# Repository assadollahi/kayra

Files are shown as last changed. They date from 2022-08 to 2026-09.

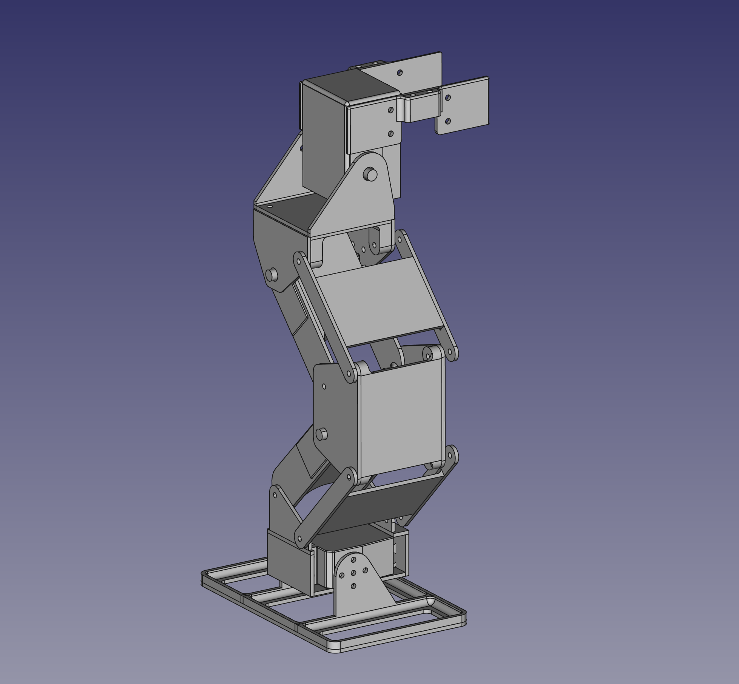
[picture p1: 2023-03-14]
Pics/kayra_assembled.png

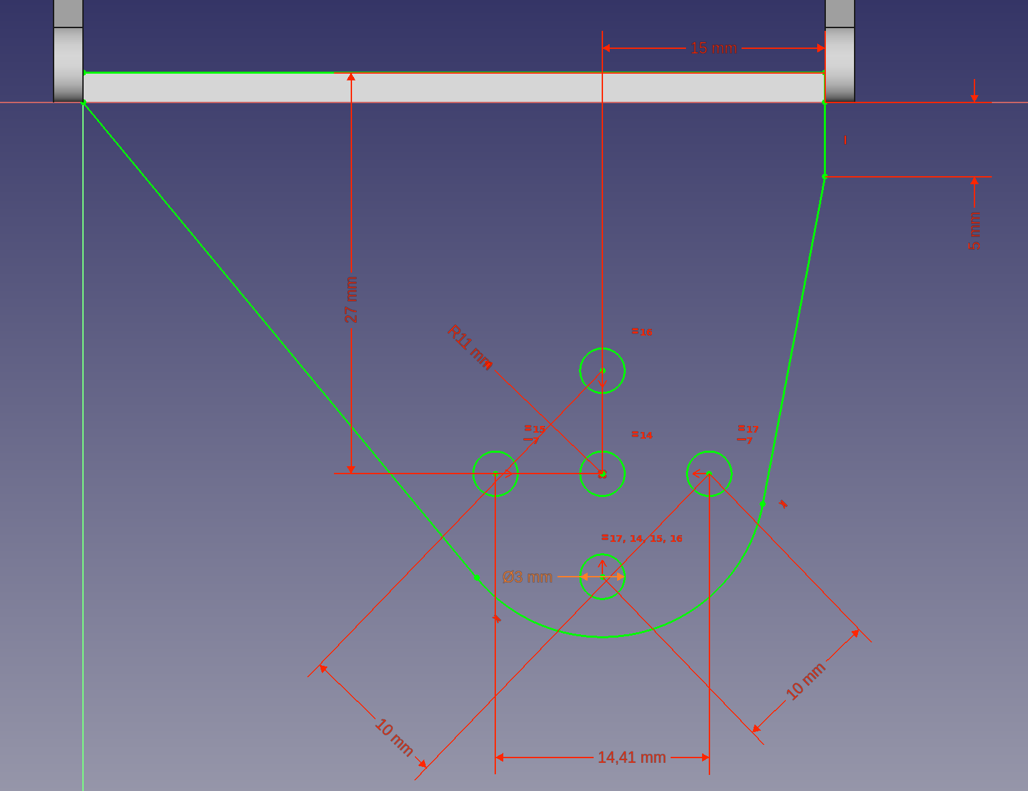
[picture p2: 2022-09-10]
Pics/5R_hipjoint_measures.png

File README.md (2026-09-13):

# kayra
An easy to modify, 3D printable open-source humanoid robot evolved by the community:

(https://youtube.com/shorts/mKMwAWRPoXo)

- goal: can walk nearly as fast as a human toddler
- goal: it can use the arms to lift at least a toy
- works immediately after building it (walking, grabbing movement patterns provided)
- is easy to charge / batteries easy to change
- can be operated by a variety of controllers (Arduino, ESP-32, etc)
- option: can also be controlled via a remote control (PS2, 8Bitdo)
- is connected to a host for Machine Learning / Computer Vision
- design should be adaptable to different servos
- modular so that enthusiasts can change the design of a subsystem
- is easy to 3D print and to assemble, ideally no soldering necessary
- easy to write software for (Python on host, Micropython on controllers)
- costs for a minimal system should be low
- simulation provided to work on the robot without any hardware at all

(https://youtu.be/ZpM4JqCai9M)

Wiring, power and how to connect the controller: [WIRING.md](WIRING.md)

Folders:
- FCStd: design files for freeCAD (Kayra is designed using the open source software freeCAD)
- gcode: printable files for Prusa i3 MK3, PETG
- Pics: some of documentation pictures
- STL: STL files for your 3D printer slicer 
- software: all software for the ESP32 Cam, Pimoroni 2040 servo-controller and host side
- MuJoCo: simulation of Kayra using the STLs in DeepMind's robot simulation software

(https://youtube.com/shorts/0EgQA_qSZeU)

For full documentation & wiki please refer to [kayra.org](https://kayra.org)
Join our [discord sever](https://discord.gg/BEGypnqF74) for discussion and support.
Follow us on [twitter](https://twitter.com/KayraHumanoid) or [instagram](https://www.instagram.com/kayrahumanoid/) for frequent updates.

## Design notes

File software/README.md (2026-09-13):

servoMap.json — which servo channel is which joint:
- the host, the servo controller and the MuJoCo simulation all talk about servos as
  an 18 float vector. servoMap.json is the single place that says what each position
  in that vector means, what the joint is called, how far it may travel and which
  MuJoCo actuator it drives.
- convention: even index = right side, odd index = left side, ordered bottom up per leg.
  0/1 ankles, 2/3 knees, 4/5 hip pitch, 6/7 hip yaw, 8..13 arms, 14/15 unused,
  16 pelvis rotation, 17 head pitch.
- servoMapLib.py is the loader used by the host software and by the simulation.
  the servo controller reads servoMap.json directly, so copy that file to the board
  next to servoConfig.json and servoControl.json. LED2 turns green when it was loaded
  and red when it is missing. without it the controller still runs, but it will not
  enforce any servo limits.
- the entries for the arms and the pelvis are marked "verified": false, they are
  inferred from the pose library and still have to be confirmed on the real robot,
  see host/tools/identifyServo.py below. the min / max values are marked
  "limitsVerified": false, they are derived from the poses in servoControl.json plus
  a margin and are not measured mechanical limits.

we have two directories host and robot:
- host is the PC with good computing capabilities, tested on Ubuntu, all software in Python
- robot is intended to run at Kayra, including Wifi connection, camera, servo controller and sensors

basic operation:
1) host/interactiveServo.py 
- should run on the Linux PC
- is for setting servo values, defining poses and defining animations
- it sends data via USB serial to the controller

2) robot/body/ usbServosCluster.py / usbServos.py 
- should run on the Pimoroni 2040 servo controller
- the Cluster variant is the current, it controls the servos via ServoCluster and can handle 18 servos, the other is the "traditional" way to control servos, but only up to 16.
- it is listening on the USB serial for commands
- it can store poses and animations on the local flash
- it allows for untethered opperation via user button and the stored animations
- rename this file on the controller to main.py to run it automatically and without Thonny IDE.

interaction of the two softwares:
- usbServos will try to load the servoConfig.json, if that's not available, LED0 on the controller will turn red otherwise green.
- usbServos will also try to load the servoControl.json, if not available LED1 = red otherwise green.
- usbServosCluster will also try to load the servoMap.json, if not available LED2 = red otherwise green. without it the servo limits are not enforced.
- the default operation mode is "untethered" (LED5 = green), i.e. the controller is not connected to the PC via USB and Kayra can perform an action when the USER button is pressed.
- long pressing the USER button will turn LED5 to blue indicating that the controller board is now in "thethered" mode and will listen to commands from the PC via USB serial.

3) host/tools/identifyServo.py:
- runs on the Linux PC, controller in tethered mode
- moves one servo channel at a time so you can see which joint it belongs to
- 'n <name>' confirms the joint of a channel, 'min' / 'max' record the mechanical
  limits after carefully jogging towards a hard stop, 'w' writes servoMap.json
- it deliberately ignores the software limits, that is the only way to widen them.
  use step size 1 near a hard stop.

4) understanding the serial ports:
- host/tools/serialPortInfo.py runs on LinuxPC and lists all available serial Ports
- robot/tools/serialSendText.py runs on the Pimoroni 2040 Servo controller and will send text to the Linux PC

5) robot/tools/i2cTest.py:
- runs on micropython devices and will list all connected i2c devices to find their address

6) robot/sensors/ imuTest.py, bno055.py, bno055_base.py:
- it is the standalone IMU readout software printing to USB serial
- the IMU is connected via i2c, hence the test code in #5.
- the code from main.py is used in #2 to read the IMU and send it to #1

setting up the host PC:

1) serial port permission. the servo controller shows up as /dev/ttyACM0, owned by
   root:dialout, so your user has to be in that group or every connection fails with
   a permission error:
     sudo usermod -aG dialout $USER
   log out and back in afterwards, group changes do not apply to running shells.

2) on Ubuntu 24.04 and later python ships without pip and without ensurepip, so
   'python3 -m venv' would create an environment with no pip in it:
     sudo apt install python3-venv

3) virtual environment, one at the top of the repository serves everything:
     python3 -m venv .venv
     source .venv/bin/activate          # or activate.fish
     pip install -r software/requirements.txt      # host: pyserial, numpy
     pip install -r mujoco/requirements.txt        # only if you want the simulation
   .venv is in .gitignore.

4) 'pip list' should now show the packages, 'pip freeze' gives you the exact
   versions if you ever need to reproduce a setup.

note: do not run python from the top of the repository without the virtual
environment, the mujoco directory shadows the mujoco library and 'import mujoco'
will silently pick up the directory instead.

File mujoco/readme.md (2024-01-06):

MuJoCo simulation of Kayra 

some older work in progress, uses keyboard input to move the simulated ankle servo:
(https://youtube.com/shorts/gwr96h01eZE)

this directory containing all the files for simulating Kayra in MuJoCo
the XML files refer via relative links to the STL files.

to install mujoco, just use pip3 install mujoco, see here for more details:
https://mujoco.readthedocs.io/en/stable/python.html

for exploring kayra's mujoco files (*.xml), start the MuJoCo viewer using 
python3 -m mujoco.viewer and load one of the XML files

assuming that you have cloned kayra's git repo to home, you can also call the viewer with a file
python3 -m mujoco.viewer --mjcf=~/kayra/mujoco/kayraLowerBody.xml

for working with plots and animations you need:
apt update && apt install -y ffmpeg
pip install -q mediapy

**tutorial how to build Kayra in MuJoCo:**
https://kayra.org/mujoco-simulating-kayra/

humanoid robots are usually built by defining the body as a trunk
of a tree then adding four limbs to the body: 
- upper arms, lowe arms, hands
- upper legs, lower legs, feet
- optionally a head

kayra is special as many limbs (esp the feet) consist of four parts,
e.g. knee, front part (shin), back part (calf) and foot joint.

this constitutes a circle and has to be reflected in the definition 
of the robot in the mujoco XML

a working example for such circles was found here
https://github.com/deepmind/mujoco/issues/172

it's the file fourBars.xml in kayra's mujoco dir, i've added gravity
so that you can see that the loops behaves mechanically correctly.

the corresponding kayra file is kayraCircle.xml, it connects:
- 4R_Link (knee) to
- 3BR_Link (calf, back part, containing the servo / actuator) to
- 2R_Link (foot joint / ankle) to
- 3FU_Link (shin, front part of the leg)

further reading:
inspirations on learning how to build a robot in mujoco:
https://studywolf.wordpress.com/2020/03/22/building-models-in-mujoco/

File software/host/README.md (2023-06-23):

interactiveServo.py 
- should run on the Linux PC
- is for setting servo values, defining poses and defining animations
- it also receives sensor data like from the IMU and (future:) the current sensor from the 2040 servo controller
- it sends data via USB serial to the controller
- in the future, the serial / USB connection will be replaced by I2C connection to the ESP32 Cam in Kayra's head that connects to the host via Wifi

clientWifi.py
- this is the first connection via WiFi to the ESP32, it can send commands via TCP sockets
- see it in action [here](https://youtube.com/shorts/rHDNVzmQHSk)

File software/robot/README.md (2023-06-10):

basic operation:
1) interactiveServo.py 
- should run on the Linux PC
- is for setting servo values, defining poses and defining animations
- it sends data via USB serial to the controller

2) usbServosCluster.py / usbServos.py 
- should run on the Pimoroni 2040 servo controller
- the Cluster variant is the current, it controls the servos via ServoCluster and can handle 18 servos, the other is the "traditional" way to control servos, but only up to 16.
- it is listening on the USB serial for commands
- it can store poses and animations on the local flash
- it allows for untethered opperation via user button and the stored animations
- rename this file on the controller to main.py to run it automatically and without Thonny IDE.

interaction of the two softwares:
- usbServos will try to load the servoConfig.json, if that's not available, LED0 on the controller will turn red otherwise green.
- usbServos will also try to load the servoControl.json, if not available LED1 = red otherwise green.
- the default operation mode is "untethered" (LED5 = green), i.e. the controller is not connected to the PC via USB and Kayra can perform an action when the USER button is pressed.
- long pressing the USER button will turn LED5 to blue indicating that the controller board is now in "thethered" mode and will listen to commands from the PC via USB serial.

3) understanding the serial ports:
- serialPortInfo.py runs on LinuxPC and lists all available serial Ports
- serialSendText.py runs on the Pimoroni 2040 Servo controller and will send text to the Linux PC

4) i2cTest.py:
- runs on micropython devices and will list all connected i2c devices to find their address

5) imuTest.py, bno055.py, bno055_base.py:
- it is the standalone IMU readout software printing to USB serial
- the IMU is connected via i2c, hence the test code in #4.
- the code from main.py is used in #2 to read the IMU and send it to #1

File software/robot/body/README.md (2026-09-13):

i2cListener.py plus i2cSlave.py 
software that listens at the i2c connection when the controller is in i2c slave mode.
for this, the i2cSlave library is used, cf https://python-academia.com/en/raspberry-pi-pico-slave/
currently, this is only for debuging the ESP32 Cam to Servo Controller connection. 
In the future, the functionality will be included in the servo control code.

these are the files for controlling the servos on the Pimoroni 2040 servo controller:
servoControl.json this contains the animations and poses that are stored on the controller for playback
servoMap.json (copy it from software/servoMap.json) says which channel drives which joint
and how far that joint may travel. usbServosCluster.py clamps every incoming servo command
to those limits, so a wrong value from the host cannot drive a joint into a hard stop.
LED2 green means the map was loaded, red means it is missing and no limits are enforced.
(servoValues.json)
usbServosCluster.py - run the controller in cluster mode (18 servos)
usbServos.py - run the controller in conventional mode (just 16 servos)
the control code currently gets the commands via serial interface and USB-C connection

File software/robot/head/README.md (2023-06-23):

This is the directory that contains the software for the ESP32 Cam.
Here, we keep the display software, the Wifi Connection and the camera server as well as the I2C connection to the body / servo controller.

commandViaWifiToI2C.py  
this is the code that receives commands via Wifi and sends them via I2C to the servo controller 
for autonomous operation, rename this file to main.py to be started after ESP32's boot up.

connectWifi.py 
this is the code that simply connects to Wifi
for autonomous operation, rename this file to booty.py to connect to Wifi at boot time and before running main.py
here, you have to specify your SSID and wifi password.
please note thate the ESP32 Cam only connects to 2.4GHz networks, not to 5GHz networks!

the tools directory contains software that 
is a simple wifi server sending / receiving data via sockets
is listing all connected i2c devices
is sending a command to a specified i2c device

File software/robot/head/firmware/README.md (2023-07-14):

we have currently three binaries to flash the ESP32 Cam board
- plain Micropython, see [here](https://micropython.org/download/esp32spiram/) also for flashing instructions  
- Micropython including camera support for streaming to the host, see [github repo](https://github.com/shariltumin/esp32-cam-micropython-2022), WiFi TLS version
- Micropython including the ST7789 display driver, [here](https://github.com/russhughes/st7789_mpy/tree/master/firmware/GENERIC_SPIRAM-7789)

flashing a binary:
- generally, the flashing procedure is done using the esptool.py, you can get it via sudo pip install esptool
- then you connect GND and IOO to put the ESP32 Cam to flash mode
- erase the flash: esptool.py --chip esp32 --port /dev/ttyUSB0 erase_flash
- and then flash with one of the binaries, e.g. esptool.py --chip esp32 --port /dev/ttyUSB0 --baud 460800 write_flash -z 0x1000 esp32-20190125-v1.10.bin 
- disconnect GND and IOO, reset the board 
- enter Thonny and connect using Run/Select Interpreter -> MicroPyton(ESP32) and the right USB port

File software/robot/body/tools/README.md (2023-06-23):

the servoClusterTest.py is derived from Pimoroni's examples: 
https://github.com/pimoroni/pimoroni-pico/tree/main/micropython/examples/servo2040

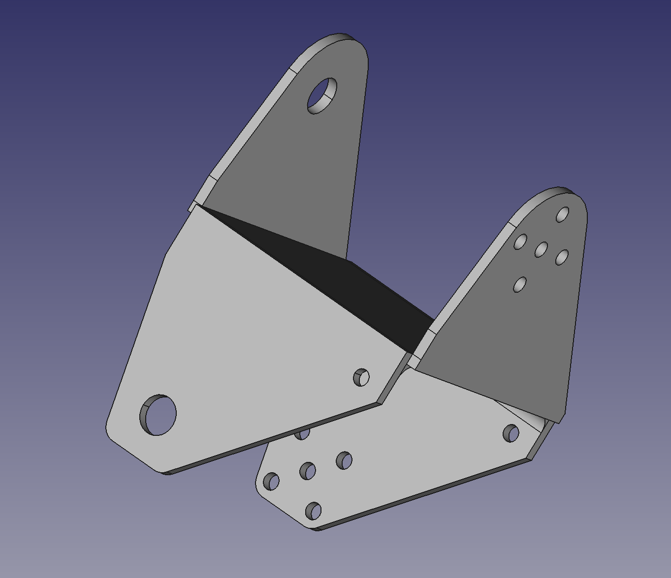
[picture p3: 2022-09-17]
Pics/5R_hipjoint_design.png

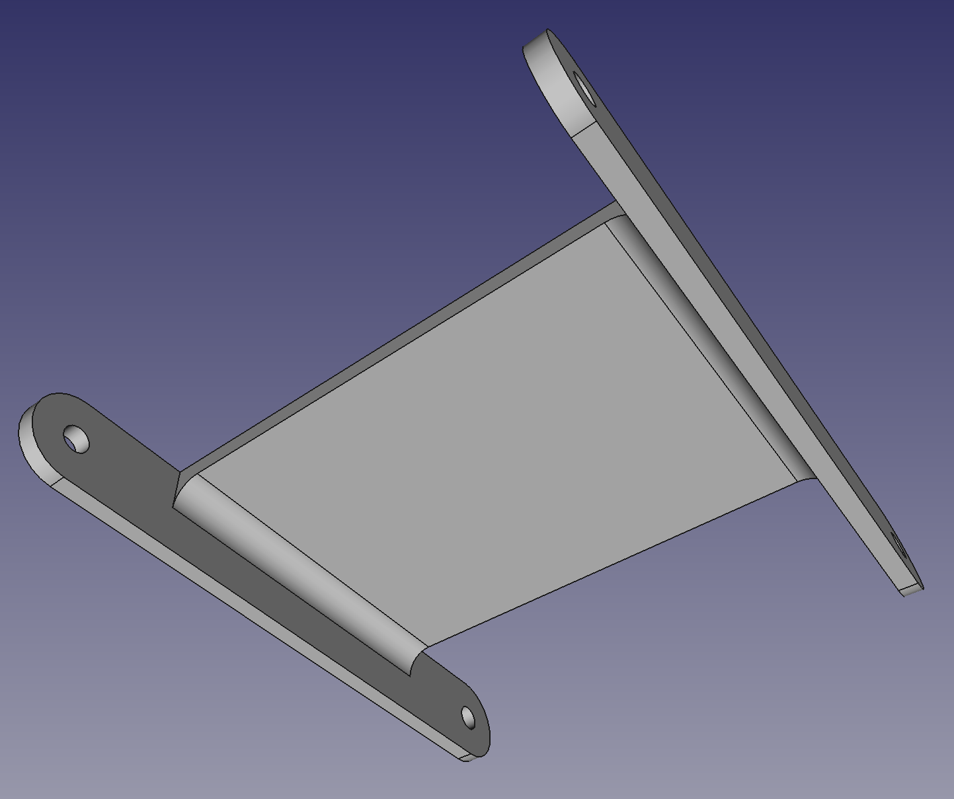
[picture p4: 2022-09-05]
Pics/3F_shin.png

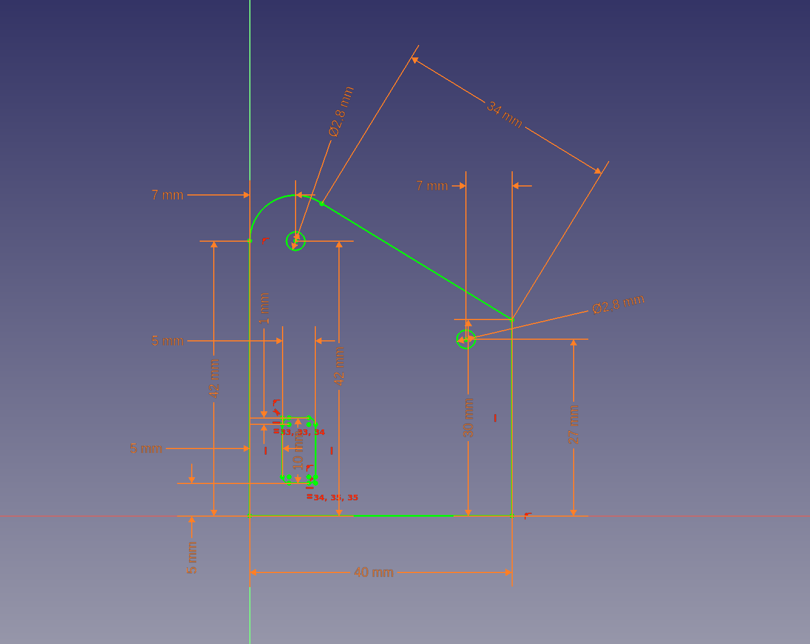
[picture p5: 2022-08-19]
Pics/anklePlate.png

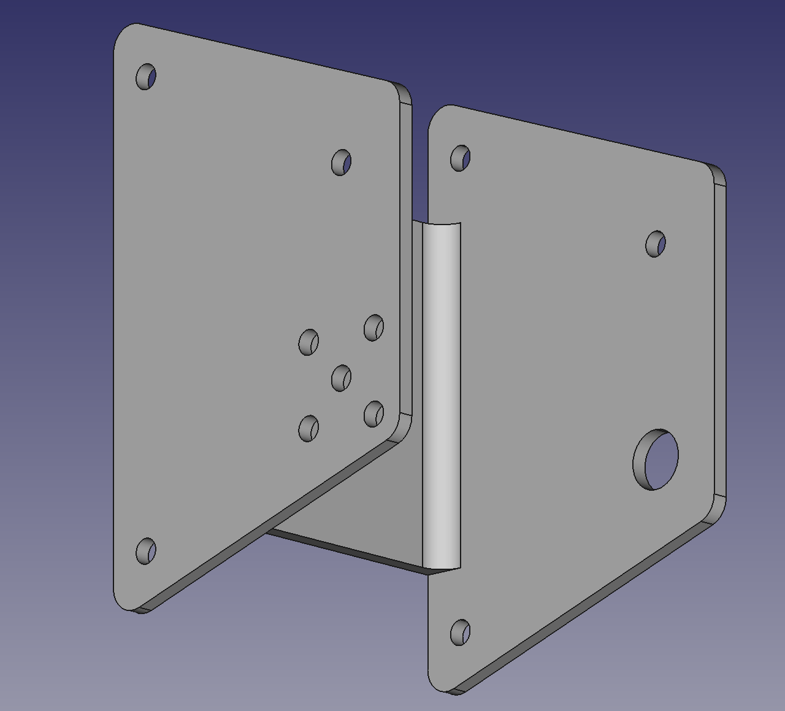
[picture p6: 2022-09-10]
Pics/4R_knee.png

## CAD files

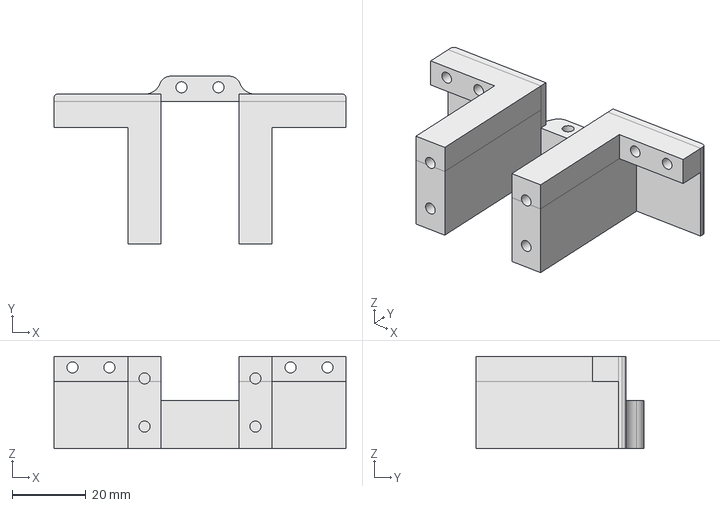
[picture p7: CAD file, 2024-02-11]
FCStd/6F_hipfront2.FCStd
79.0 x 45.4 x 25.0 mm

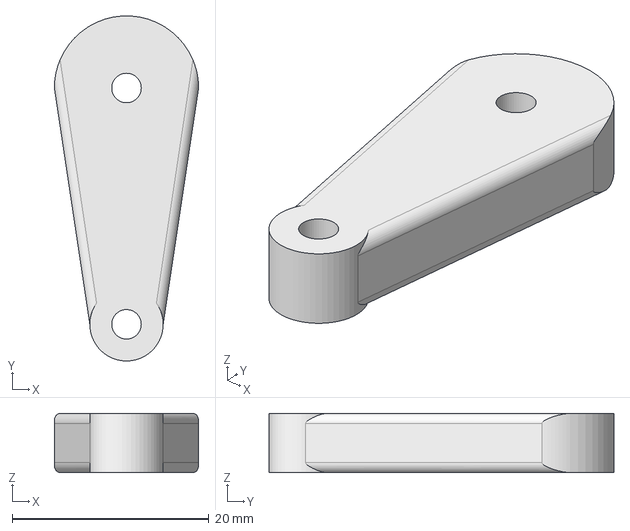
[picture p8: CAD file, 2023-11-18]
FCStd/prototypes/servoHorn.FCStd
14.6 x 35.0 x 6.00 mm

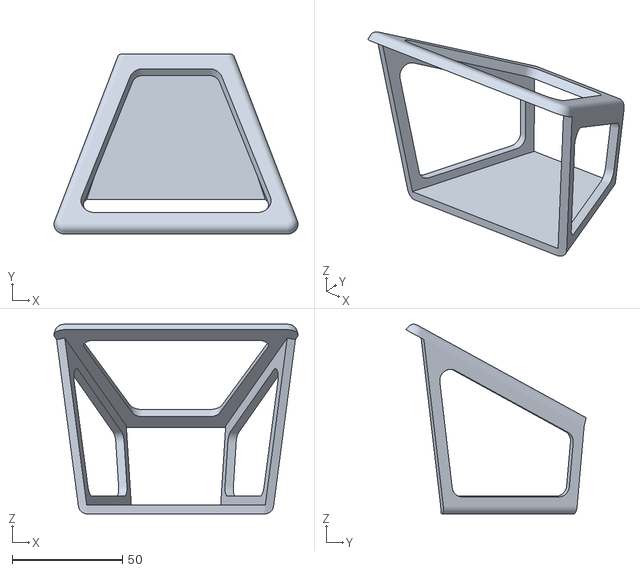
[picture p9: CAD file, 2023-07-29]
STL/prototypes/TVHead-Body.stl
110.6 x 81.7 x 86.0

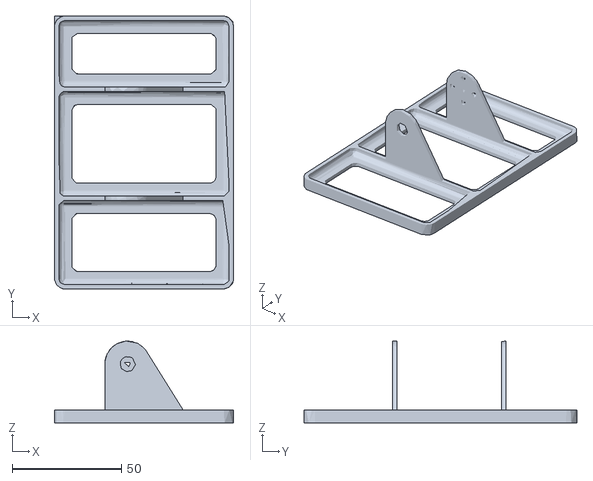
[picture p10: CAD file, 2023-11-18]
STL/simplified/1L_foot-Body_simplified.stl
82.0 x 125.0 x 37.5

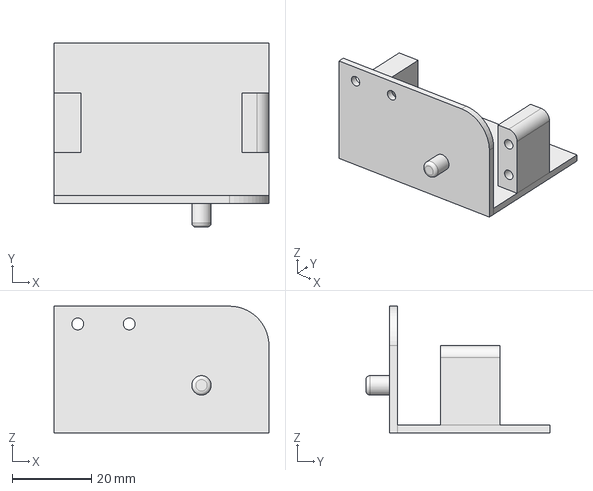
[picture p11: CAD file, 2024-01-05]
FCStd/6R_hip_bearing.FCStd
54.3 x 46.5 x 32.0 mm

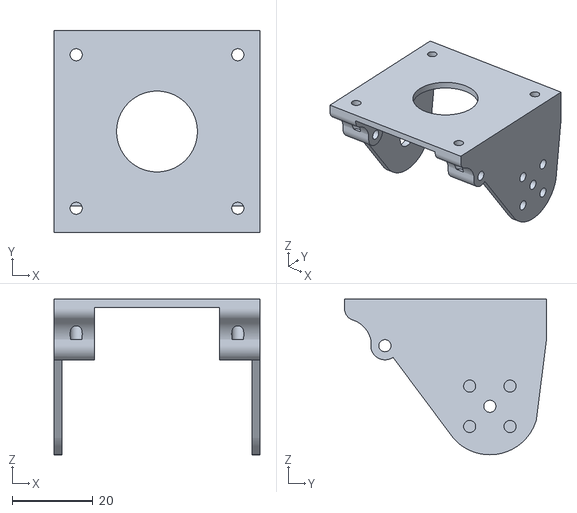
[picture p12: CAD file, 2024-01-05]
STL/5R_hipjoint_lower-Body.stl
51.0 x 50.0 x 38.5

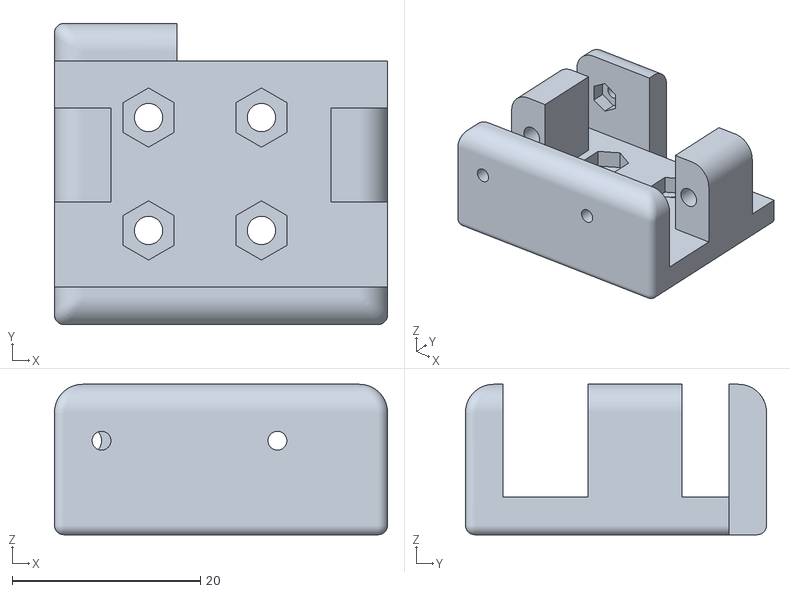
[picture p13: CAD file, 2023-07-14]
STL/prototypes/headSmallServoHolder-Body.stl
35.4 x 32.0 x 16.0

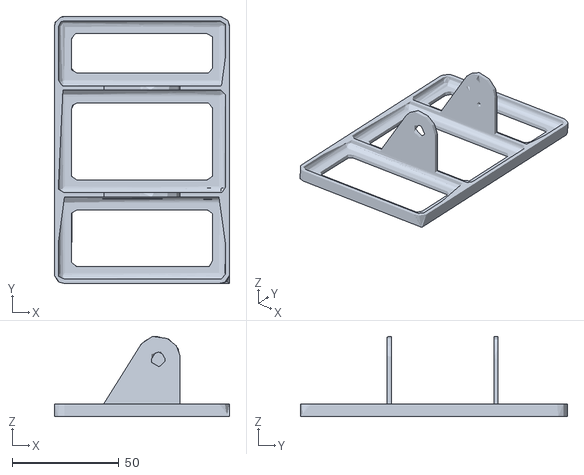
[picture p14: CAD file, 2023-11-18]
STL/simplified/1R_foot-Body_simplified.stl
82.0 x 125.0 x 37.6

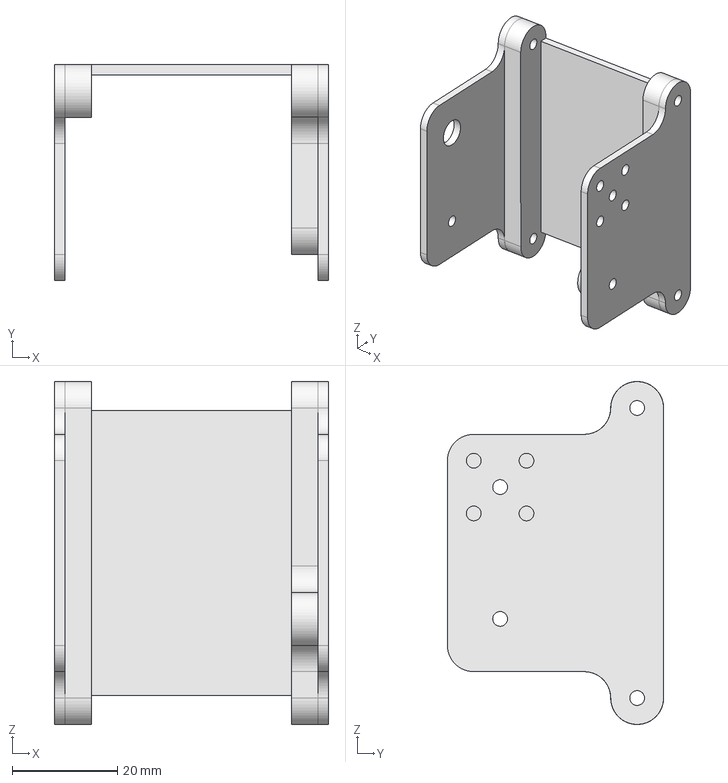
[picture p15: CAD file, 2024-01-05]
FCStd/4R_knee.FCStd
52.0 x 41.0 x 65.0 mm

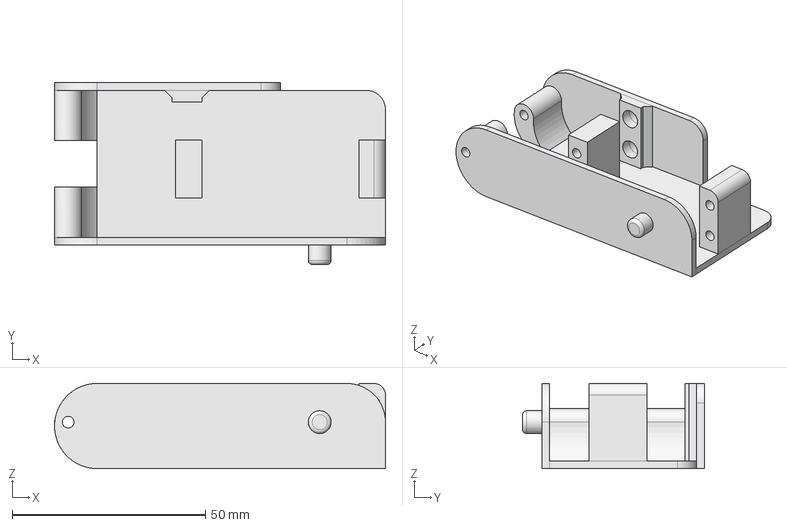
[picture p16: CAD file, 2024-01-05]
FCStd/3BR_calf.FCStd
85.5 x 47.0 x 22.0 mm

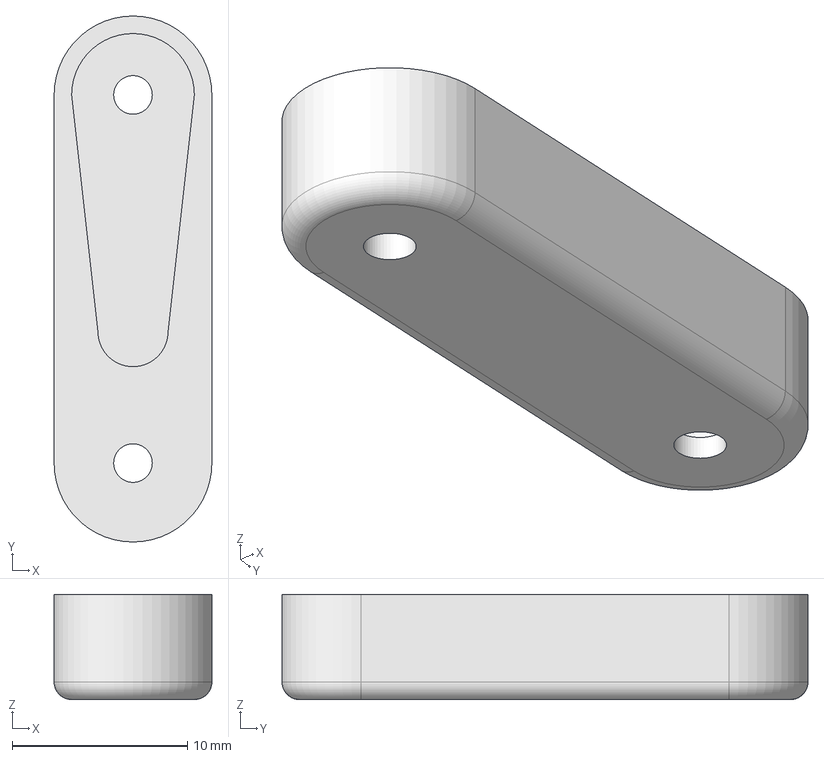
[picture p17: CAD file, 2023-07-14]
FCStd/prototypes/neckHornSmallHollow2.FCStd
9.00 x 30.0 x 6.00 mm

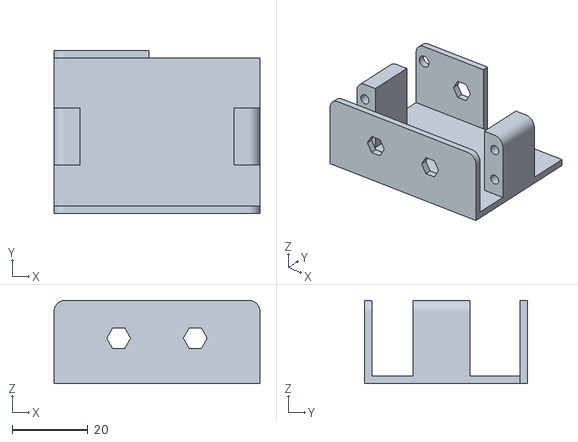
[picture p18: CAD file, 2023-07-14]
STL/prototypes/headServoHolder-Body.stl
54.3 x 43.0 x 22.0

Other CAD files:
STL/6F_hipfront2-Body.stl
FCStd/prototypes/TVHead.FCStd
FCStd/prototypes/headSmallServoHolder.FCStd
STL/6R_hip_bearing-Body.stl
STL/prototypes/servoHorn-Body.stl
STL/5L_hipjoint_lower-Body.stl
FCStd/10L_lower_arm.FCStd
FCStd/10R_lower_arm.FCStd
FCStd/1L_foot.FCStd
FCStd/1L_foot_bearing.FCStd
FCStd/1R_foot.FCStd
FCStd/1R_foot_bearing.FCStd
FCStd/2L_footJoint.FCStd
FCStd/2L_footJoint_bearing.FCStd
FCStd/2R_footJoint.FCStd
FCStd/2R_footJoint_bearing.FCStd
FCStd/3BL_calf.FCStd
FCStd/3FU_shin.FCStd
FCStd/3F_shin.FCStd
FCStd/4L_knee.FCStd
FCStd/5L_hipjoint_lower.FCStd
FCStd/5L_hipjoint_upper.FCStd
FCStd/5L_hipjoint_upper_bearing.FCStd
FCStd/5R_hipjoint_lower.FCStd
FCStd/5R_hipjoint_upper.FCStd
FCStd/5R_hipjoint_upper_bearing.FCStd
FCStd/6F_hipback.FCStd
FCStd/6F_hipfront.FCStd
FCStd/6L_hip.FCStd
FCStd/6L_hip_bearing.FCStd
FCStd/6R_hip.FCStd
FCStd/7B_chestback_controller.FCStd
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

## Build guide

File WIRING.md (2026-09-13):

# Wiring Kayra

How to get power and signals into the robot. This is a living document, it grows as
we build. Everything here refers to the Pimoroni Servo 2040 as the body controller.

> Work on the wiring with the battery disconnected. Connect the battery last, after
> you have checked the polarity of every connection.

## 1. Power

Kayra needs **two power rails**: a fat one for the servos and a small one for the
controller logic. They are separate on our boards, see the note below.

```
                 +--------------------+   servo voltage    +----------------+
  battery  --+-->|  UBEC / BEC  10 A  |------------------->| screw terminal |
             |   +--------------------+                    |  Servo 2040    |
             |                                             |                |
             |   +--------------------+   5 V              |  5V / GND pads |
             +-->|  small 5 V BEC     |------------------->|  (by Qwiic)    |
                 +--------------------+                    +----------------+
                                                   common ground everywhere
```

### The "Separate USB and Ext. Power" trace

On the back of the Servo 2040 there is a small trace labelled *Separate USB and
Ext. Power*, it looks like a dumb bell. From the factory it is **closed**, which ties
the screw terminal rail to the USB 5 V rail.

**On our board this trace is already cut.** That has two consequences:

- external power feeds the **servos only**, it can never push current back into the
  PC's USB port, and you may use servos above 5 V without damaging the RP2040
- the board gets **no logic power from the screw terminals**. It boots only from USB
  or from the 5 V / GND solder pads next to the Qwiic connector

So for **untethered operation** (USER button, no PC attached) you *must* feed 5 V into
those solder pads, otherwise the board simply stays dark. This is the single most
common reason for "the robot does nothing when I press the button".

### Sizing

- the Servo 2040 is not designed to distribute much more than **10 A**
- 18 servos at stall would be far more than that, but you never reach it in practice.
  A 10 A UBEC is a reasonable choice and usefully acts as a current limiter
- walking loads the servos much harder than standing, so do not size for idle current
- servo voltage: whatever the servos are rated for. The board supports up to 11 V now
  that the trace is cut. TODO: note the exact servos and voltage we settled on

## 2. Servo channels

The servo headers are numbered **1 to 18** on the silkscreen. The software counts
from **0**, so:

```
  board header 1  ==  software channel 0
  board header 18 ==  software channel 17
```

Which channel is which joint is defined in [`software/servoMap.json`](software/servoMap.json).
Short version, even = right, odd = left, bottom up per leg:

| channels | joints |
|---|---|
| 0, 1 | ankles R / L |
| 2, 3 | knees R / L |
| 4, 5 | hip pitch R / L |
| 6, 7 | hip yaw R / L |
| 8 .. 13  | arms, 3 per side (shoulder rotation, brace, elbow) |
| 14, 15 | unused |
| 16 | pelvis rotation |
| 17 | head pitch |

The arm and pelvis assignments are still marked `"verified": false` in the map. Confirm
them on the robot with:

```bash
python3 software/host/tools/identifyServo.py
```

Watch the silkscreen for the orientation of the three pin servo connectors, do not go by
cable colour alone.

## 3. IMU (BNO055)

Connected to **i2c0** at 400 kHz:

| BNO055 | Servo 2040 |
|---|---|
| SDA | GP20 |
| SCL | GP21 |
| VIN | 3V3 |
| GND | GND |

Default address is `0x28`. To check that the board sees it, run
`software/robot/tools/i2cTest.py` on the controller, it scans the bus and prints every
address it finds.

## 4. USB to the host

USB-C from the Servo 2040 to the PC, 115200 baud. Used for:

- flashing and the Thonny REPL
- `software/host/interactiveServo.py`, the pose and animation editor
- `software/host/tools/identifyServo.py`
- the IMU readings the controller prints back to the host

`software/host/tools/serialPortInfo.py` lists the available ports if you are unsure
which one appeared.

## 5. Reading the LED bar

The controller reports its state on the WS2812 bar at boot:

| LED | green | red | blue |
|-----|---|-----|---|
| 0 | `servoConfig.json` loaded | missing | |
| 1 | `servoControl.json` loaded | missing | |
| 2 | `servoMap.json` loaded | missing, **no servo limits are enforced** | |
| 5 | untethered mode | operation mode unknown | tethered mode |

A long press on the USER button in untethered mode switches back to tethered and turns
LED5 blue.

Copy all three JSON files to the board next to `main.py`.

## 6. Still to document

- the exact servos, their voltage and the battery we settle on
- battery mounting and the charging / swapping procedure
- ESP32 cam in the head, its I2C link to the body controller (currently out of scope)
- current and voltage sensing on the servo rail, the Servo 2040 can measure both and
  it would tell us about brownouts during walking

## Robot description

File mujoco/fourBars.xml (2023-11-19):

<mujoco>
    <!-- option gravity="0 0 0" timestep="0.002" /-->
    <asset>
        <material name="blue_" rgba="0 0 1 1" />
        <material name="green" rgba="0 1 0 1" />
        <material name="red__" rgba="1 0 0 1" />
        <material name="white" rgba="1 1 1 1" />
    </asset>
    <worldbody>
        <geom type="plane" size="10 10 0.1" pos="0 0 -2" rgba=".9 0 0 1" />
        <light diffuse=".5 .5 .5" pos="0 0 3" dir="0 0 -1" />
        <body name="link_1" pos="0 0 0">
            <geom type="cylinder" size=".2 2" pos="0 0 2" euler="0 0 0" material="red__" />
            <geom type="cylinder" size=".25 .25" pos="0 0 4" euler="0 90 0" material="red__" />
            <geom type="cylinder" size=".25 .25" pos="0 0 0" euler="0 90 0" material="red__" />
            <body name="link_2" pos="0.5 0 0" euler="0 0 0">
                <joint name="hinge_1" pos="0 0 0" axis="1 0 0" />
                <geom type="cylinder" size=".2 2" pos="0 2 0" euler="90 0 0" material="blue_" />
                <geom type="cylinder" size=".25 .25" pos="0 4 0" euler="0 90 0" material="blue_" />
                <geom type="cylinder" size=".25 .25" pos="0 0 0" euler="0 90 0" material="blue_" />
                <body name="link_3" pos="-0.5 4 0" euler="0 0 0">
                    <joint name="hinge_2" pos="0 0 0" axis="1 0 0" />
                    <geom type="cylinder" size=".2 2" pos="0 0 2" euler="0 0 0" material="green" />
                    <geom type="cylinder" size=".25 .25" pos="0 0 0" euler="0 90 0" material="green" />
                    <geom type="cylinder" size=".25 .25" pos="0 0 4" euler="0 90 0" material="green" />
                    <body name="link_4" pos="0.5 0 4" euler="0 0 0">
                        <joint name="hinge_3" pos="0 0 0" axis="1 0 0" />
                        <geom type="cylinder" size=".2 2" pos="0 -2 0" euler="90 0 0" material="white" />
                        <geom type="cylinder" size=".25 .25" pos="0 0 0" euler="0 90 0" material="white" />
                        <geom type="cylinder" size=".25 .25" pos="0 -4 0" euler="0 90 0" material="white" />
                    </body>
                </body>
            </body>
        </body>
    </worldbody>
    <equality>
        <connect name="kinematic_link" active="true" body1="link_1" body2="link_4" anchor="0 0 4" />
    </equality>
</mujoco>

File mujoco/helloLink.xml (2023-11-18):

<mujoco model="hello">
  <option gravity="0 0 -9.81"/>


  <worldbody>
    <light pos="0 0 5" dir="0 0 -1" diffuse="0.3 0.3 0.3"/>
    <geom name="floor" size="0 0 0.05" rgba="1.0 0.0 0.0 1.0" type="plane"/>

     <body name="base" pos="0 0 0.6">
            <geom name="link0" type="box" size="0.1 0.2 0.6" rgba="0.0 1.0 1.0 1.0" pos="0 0 0"/>
            <inertial pos="0 0 0" mass="0.1" diaginertia="0 0 0"/>
 
            <!-- nest each child piece inside the parent body tags -->
            <body name="link1" pos="-0.1 0 1.2">
                <!-- this joint connects link1 to the base -->
                <joint name="joint0" type="hinge" axis="0 -1 0" pos="0.0 0.0 -0.6"/>
 
                <geom name="link1" type="box" size="0.1 0.2 0.6" rgba="0.0 1.0 0.0 1.0" pos="0 0 0" euler="0 3.14 0"/>
                <inertial pos="0 0 0" mass="0.1" diaginertia="1 1 1"/>
 
                <body name="link2" pos="0.05 0 1.2">
                    <!-- this joint connects link2 to link1 -->
                    <joint name="joint1" type="hinge" axis="0 -1 0" pos="0 0 -0.6"/>
 
                    <geom name="link2" type="box" size="0.1 0.2 0.6" rgba="1.0 1.0 0.0 1.0" pos="0 0 0" euler="0 3.14 0"/>
                    <inertial pos="0 0 0" mass="0.1" diaginertia="1 1 1"/>
 
                    <!-- the ABR Control Mujoco interface uses the EE body to -->
                    <!-- identify the end-effector point to control with OSC-->
                    <body name="EE" pos="0 0.2 0.2">
                        <inertial pos="0 0 0" mass="0" diaginertia="0 0 0" />
                    </body>
                </body>
            </body>
        </body>
    </worldbody>
 
    <actuator>
        <motor name="joint0_motor" joint="joint0"/>
        <motor name="joint1_motor" joint="joint1"/>
    </actuator>


</mujoco>

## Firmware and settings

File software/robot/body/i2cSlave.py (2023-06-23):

### i2cSlave.py
from machine import mem32,mem8,Pin

class i2c_slave:
    I2C0_BASE = 0x40044000
    I2C1_BASE = 0x40048000
    IO_BANK0_BASE = 0x40014000

    mem_rw = 0x0000
    mem_xor = 0x1000
    mem_set = 0x2000
    mem_clr = 0x3000

    IC_CON = 0 #I2C Control Register
    IC_TAR = 4 #I2C Target Address Register
    IC_SAR = 8 #I2C Slave Address Register

    IC_DATA_CMD = 0x10 #I2C Rx/Tx Data Buffer and Command Register

    IC_RAW_INTR_STAT = 0x34 # I2C Raw Interrupt Status Register

    IC_RX_TL = 0x38 #I2C Receive FIFO Threshold Register
    IC_TX_TL = 0x3C #I2C Transmit FIFO Threshold Register

    IC_CLR_INTR = 0x40 #Clear Combined and Individual Interrupt Register

    IC_CLR_RD_REQ = 0x50
    IC_CLR_TX_ABRT = 0x54

    IC_ENABLE = 0x6c #I2C ENABLE Register
    IC_STATUS = 0x70 #I2C STATUS Register


    def write_reg(self, reg, data, method=0):
        mem32[ self.i2c_base | method | reg] = data

    def set_reg(self, reg, data):
        self.write_reg(reg, data, method=self.mem_set)

    def clr_reg(self, reg, data):
        self.write_reg(reg, data, method=self.mem_clr)

    def __init__(self, i2cID = 0, sda=0, scl=1, slaveAddress=0x41):
        self.scl = scl
        self.sda = sda
        self.slaveAddress = slaveAddress
        self.i2c_ID = i2cID
        if self.i2c_ID == 0:
            self.i2c_base = self.I2C0_BASE
        else:
            self.i2c_base = self.I2C1_BASE

        # 1 Disable DW_apb_i2c
        self.clr_reg(self.IC_ENABLE, 1)

        # 2 set slave address
        # clr bit 0 to 9
        # set slave address
        self.clr_reg(self.IC_SAR, 0x1ff)
        self.set_reg(self.IC_SAR, self.slaveAddress &0x1ff)

        # 3 write IC_CON 7 bit, enable in slave-only
        self.clr_reg(self.IC_CON, 0b01001001)
        # set SDA PIN
        mem32[ self.IO_BANK0_BASE | self.mem_clr | ( 4 + 8 * self.sda) ] = 0x1f
        mem32[ self.IO_BANK0_BASE | self.mem_set | ( 4 + 8 * self.sda) ] = 3
        # set SLA PIN
        mem32[ self.IO_BANK0_BASE | self.mem_clr | ( 4 + 8 * self.scl) ] = 0x1f
        mem32[ self.IO_BANK0_BASE | self.mem_set | ( 4 + 8 * self.scl) ] = 3

        # 4 enable i2c
        self.set_reg(self.IC_ENABLE, 1)

    def anyRead(self):
        status = mem32[ self.i2c_base | self.IC_RAW_INTR_STAT] & 0x20
        if status :
            return True
        return False

    def put(self, data):
        # reset flag
        self.clr_reg(self.IC_CLR_TX_ABRT,1)
        status = mem32[ self.i2c_base | self.IC_CLR_RD_REQ]
        mem32[ self.i2c_base | self.IC_DATA_CMD] = data & 0xff

    def any(self):
        # get IC_STATUS
        status = mem32[ self.i2c_base | self.IC_STATUS]
        # check RFNE receive fifio not empty
        if (status & 8) :
            return True
        return False

    def get(self):
        while not self.any():
            pass
        return mem32[ self.i2c_base | self.IC_DATA_CMD] & 0xff



    if __name__ == "__main__":
        import utime
        from machine import mem32
        from i2cSlave import i2c_slave

        s_i2c = i2c_slave(0,sda=0,scl=1,slaveAddress=0x41)
        counter =1
        try:
            while True:
                if s_i2c.any():
                    print(s_i2c.get())
                if s_i2c.anyRead():
                    counter = counter + 1
                    s_i2c.put(counter & 0xff)

        except KeyboardInterrupt:
            pass

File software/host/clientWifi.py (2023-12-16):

#import network
import socket

#wlan_sta = network.WLAN(network.STA_IF)
#if wlan_sta.isconnected():
#    print("wifi is connected")

thisHost = socket.gethostname()
thisIPAddr =  socket.gethostbyname(thisHost)
print("this host: " + thisHost + " ip: " + thisIPAddr)

# Create STREAM TCP socket
s = socket.socket(socket.AF_INET, socket.SOCK_STREAM)

sockaddr = socket.getaddrinfo('192.168.0.100', 8000)[0][-1]
print("connecting to:", sockaddr)

s.connect(sockaddr)

def sendText(textToSend):
   s.send(textToSend.encode()) 
   
   data = ''
   data = s.recv(1024).decode()
   print ("received: " + data)
   

while True:
   enteredText = input('enter: ')
   sendText(enteredText)

   if(enteredText == "exit"):
        break

s.close ()

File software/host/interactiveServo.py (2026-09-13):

# this is intended to be run from a PC

import curses
import curses.ascii
import copy
import os
import sys
import serial
import serial.tools.list_ports
import time
import json
import numpy as np

sys.path.insert(0, os.path.join(os.path.dirname(os.path.abspath(__file__)), ".."))
from servoMapLib import loadServoMap

# which servo channel drives which joint, and the software limits
servoMap = loadServoMap()

# connections
currentPort = 0 # first serial port 
serialPort = -1
serialSelected = False

# servos
servoNumber = 0 # current servo to be controlled
servoValues = [0.0] * servoMap.servoCount # storing all servo values
servoStep = 10 # moving servo by this angle on key press

# poses
poseName = "neutral" # name of the current pose
poseHighlighted = "" # for editing animations
poseNumber = 0
poseDictionary = {} # dictionary of posture names and their servoValues
poseDictionary[poseName] = copy.deepcopy(servoValues)

# animation
animationName = "first"
animationStep = 0
animationPlaying = False
animationDictionary = {}
animationDictionary.update({animationName : [poseName]}) # first animation consists of the neutral pose only

# control states
inputMode = "connect" # what state should receive the keyboard input
textEntered = "" # when entering a text, store it here across key strokes
textIntent = "" # use the entered text for this intent 

def getOrderedListOfSimilarPosesForPose(basePoseName, inListOfPoses):
    baseServoValues = np.array(inListOfPoses[basePoseName])

    # compute all euclidean distances
    compareDictionary = {}
    for eachPoseName in inListOfPoses:
        compareServoValues = np.array(inListOfPoses[eachPoseName])

        euclideanDistance = np.linalg.norm(baseServoValues - compareServoValues)
        compareDictionary[eachPoseName] = euclideanDistance

    # now sort the dictionary by distance
    poseNameList = list(compareDictionary.keys())
    euclideanDistanceList = list(compareDictionary.values())
    sorted_value_index = np.argsort(euclideanDistanceList)
    sorted_dict = {poseNameList[i]: euclideanDistanceList[i] for i in sorted_value_index}

    return sorted_dict

def similarPosesDictToStr(inSimilarPosesDic):
    outStr = "similar poses: "

    poseCounter = 0
    for eachKey in inSimilarPosesDic:
        if poseCounter > 0:
            outStr += eachKey + " " + f"{inSimilarPosesDic[eachKey]:.2f}" + " "
        poseCounter += 1
        if poseCounter > 7:
            break

    return outStr

def sendCommand(inCommand):
    # this should be the only place where commands are sent 
    # so this would be the place to connect to other controllers
    global serialPort

    '''
    if serialPort == -1:
        inputMode = "connect"
    else:
    '''    
    serialPort.write((inCommand + "\n").encode('ASCII'))

def setAllServos(inServoValues):
    # never send a pose that would drive a joint past its software limits
    clampedValues = servoMap.clampAll(inServoValues)
    stringValues = [str(x) for x in clampedValues] 
    sendCommand("sas " + " ".join(stringValues) + "\n")   

def storeNamedPose(inPoseName, inServoValues):
    stringValues = [str(x) for x in inServoValues] 
    sendCommand("snp " + inPoseName + " " + " ".join(stringValues) + "\n")

def storeSingleAnimation(inAnimName, inListOfPoses, inPoseDictionary):
    # store single anmiation, i.e. name and list of poses
    
    # send animation's poses first
    for eachPose in inListOfPoses:
        storeNamedPose(eachPose, inPoseDictionary[eachPose])
        
    # next, send the animation name together with the sequence of poses    
    sendCommand("ssa " + inAnimName + " " + " ".join(inListOfPoses) + "\n") 

def playSingleAnimation(inAnimName):
    # play single animation
    sendCommand("psa " + inAnimName + "\n") 

def setUntetheredAnimation(inAnimName):
    # set animation to be played when untethered and user button is pressed
    sendCommand("tua " + inAnimName + "\n")

def setSingleServoClamped(inServoNumber, inServoValue):
    # keep the servo inside the limits from servoMap.json and report what happened
    clampedValue = servoMap.clamp(inServoNumber, inServoValue)

    sendCommand("sss " + str(inServoNumber) + " " + str(clampedValue))

    outStr = "servo " + str(inServoNumber) + " (" + servoMap.describe(inServoNumber) + ") set to " + str(clampedValue)
    if clampedValue != inServoValue:
        limitMin, limitMax = servoMap.limits(inServoNumber)
        outStr += "   [limited to " + str(limitMin) + ".." + str(limitMax) + "]"

    return clampedValue, outStr

def controlUI(stdscr):

    global currentPort, serialPort, serialSelected
    global servoNumber, servoValues, servoStep
    global poseDictionary, poseName, poseHighlighted, poseNumber
    global animationNumber, animationName, animationDictionary, animationStep
    global inputMode, textEntered, textIntent

    cursorX = 0
    cursorY = 0
    
    curses.start_color()
    curses.init_pair(1, curses.COLOR_GREEN, curses.COLOR_BLACK)
    curses.init_pair(2, curses.COLOR_RED, curses.COLOR_BLACK)    
    curses.curs_set(0) 
    stdscr.nodelay(1)
    
    imuData = ""

    while True:

        if serialSelected == True:
            #stdscr.addstr(20, 4, "serial connection established") 
        
            if serialPort.inWaiting() > 0:
            
                '''    
                # Read data out of the buffer until a carraige return / new line is found
                serialString = ""
                while True:
                    ch = serialPort.read()
                    serialString += chr(int(ch))
                    if ch=='\r' or ch=='':
                        break

                #serialString = serialPort.read(3) #readline()
                '''
                ser_bytes = serialPort.readline()
                imuData = ser_bytes[0:len(ser_bytes)-2].decode("utf-8")
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

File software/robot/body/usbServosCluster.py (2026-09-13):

import sys
import gc
import time
import math
import json
import uselect
from pimoroni import Button
from plasma import WS2812
from servo import ServoCluster, servo2040
from bno055 import *


"""
- create servo cluster
- control it together via serial commands from PC.
- uses code from pimoroni servo 2040 examples to move servos smoothly
"""
# connect IMU
sda=machine.Pin(20) # Explorer 20 Breakout 4
scl=machine.Pin(21) # Explorer 21 Breakout 5
i2c=machine.I2C(0,sda=sda, scl=scl, freq=400000)

imuInstalled = False
try:
    imu = BNO055(i2c)
    calibrated = False
    imuInstalled = True
except:
    print("no IMU installed")

# Create the LED bar, using PIO 1 and State Machine 0
led_bar = WS2812(servo2040.NUM_LEDS, 1, 0, servo2040.LED_DATA)

# Create a list of servos for pins 0 to 3. Up to 16 servos can be created
START_PIN = servo2040.SERVO_1
END_PIN = servo2040.SERVO_18
servos = ServoCluster(pio=0, sm=0, pins=list(range(START_PIN, END_PIN + 1)))

# Enable all servos (this sets them to middle position)
servos.enable_all()
time.sleep(0.5)

# servo speeds
TOTAL_SERVOS = 18
UPDATES = 50            # How many times to update Servos per second
TIME_FOR_EACH_MOVE = 0.50  # The time to travel between each value. 32 is nice, used to be 25, lower numbers make the robot faster
UPDATES_PER_MOVE = TIME_FOR_EACH_MOVE * UPDATES # 50 * 0.32 = 16
USE_COSINE = False       # Whether or not to use a cosine path between values

# software limits per channel, filled from servoMap.json below.
# defaults are wide open so that the firmware still runs without the map file.
servoMin = [-90.0] * TOTAL_SERVOS
servoMax = [90.0] * TOTAL_SERVOS
servoEnabled = [True] * TOTAL_SERVOS

# servos & poses
servoValues = [0.0] * TOTAL_SERVOS # servo values for the current posture
nextServoValues = [0.0] * TOTAL_SERVOS # servo values for the next posture provided by SAS command
poseDictionary = {} # dictionary of posture names and their servoValues
poseName = "crouch"
untetheredStartPose = "crouch"

# animation
animationDictionary = {} # dictionary of animation names and their list of poses
animationToPlay = "first"

# button for untethered mode
user_sw = Button(servo2040.USER_SW)
operationMode = "tethered"

# led bar for status display
led_bar.start()

def sendIMUToHost():
    if imuInstalled == True:
            
        '''
        if not calibrated:
            calibrated = imu.calibrated()
            print('Calibration required: sys {} gyro {} accel {} mag {}'.format(*imu.cal_status()))
        print('Temperature {}°C'.format(imu.temperature()))
        print('Mag       x {:5.0f}    y {:5.0f}     z {:5.0f}'.format(*imu.mag()))
        print('Gyro      x {:5.0f}    y {:5.0f}     z {:5.0f}'.format(*imu.gyro()))
        print('Accel     x {:5.1f}    y {:5.1f}     z {:5.1f}'.format(*imu.accel()))
        print('Lin acc.  x {:5.1f}    y {:5.1f}     z {:5.1f}'.format(*imu.lin_acc()))
        print('Gravity   x {:5.1f}    y {:5.1f}     z {:5.1f}'.format(*imu.gravity()))
        '''
        print('Heading     {:4.0f} roll {:4.0f} pitch {:4.0f}'.format(*imu.euler()))

def clampServo(inServoNumber, inServoValue):
    # keep one servo inside the limits from servoMap.json
    if not servoEnabled[inServoNumber]:
        return 0.0
    if inServoValue < servoMin[inServoNumber]:
        return servoMin[inServoNumber]
    if inServoValue > servoMax[inServoNumber]:
        return servoMax[inServoNumber]
    return inServoValue

def clampServoValues(inServoValues):
    # clamp a whole pose in place, the host may send anything
    for eachServoNumber in range(0, TOTAL_SERVOS):
        inServoValues[eachServoNumber] = clampServo(eachServoNumber, inServoValues[eachServoNumber])

def setSingleServo(inServos, inServoNumber, inServoValue):
    # set servo value
    inServos.value(inServoNumber, clampServo(inServoNumber, inServoValue))
                        
    # give servo time to react
    time.sleep(0.1)
    # send new data IMU to host
    sendIMUToHost() 

def setAllServos(inServos, inServoValues, inNextServoValues):

    # the interpolation walks towards inNextServoValues, so that is what has to be safe
    clampServoValues(inNextServoValues)

    for update in range(0, UPDATES_PER_MOVE):
        # Calculate how far along this movement to be
        percent_along = update / UPDATES_PER_MOVE

        if USE_COSINE:
            # Move the servo between values using cosine
            for eachServoNumber in range(0,TOTAL_SERVOS):
                inServos.to_percent(eachServoNumber, math.cos(percent_along * math.pi), 1.0, -1.0, inServoValues[eachServoNumber], inNextServoValues[eachServoNumber])
        else:
            # Move the servo linearly between values
            for eachServoNumber in range(0,TOTAL_SERVOS):
                inServos.to_percent(eachServoNumber, percent_along, 0.0, 1.0, inServoValues[eachServoNumber], inNextServoValues[eachServoNumber])                
        
        time.sleep(1.0 / UPDATES)
        # send new data IMU to host
        sendIMUToHost() 

def writeConfig():
    configDictionary = {} # store configuration: operation mode, initial pose, animation to play    
    configDictionary["operationMode"] = operationMode
    configDictionary["initialPose"] = untetheredStartPose
    configDictionary["animationToPlay"] = animationToPlay    

    with open("servoConfig.json", "w") as outfile:
        json.dump(configDictionary, outfile)
        
    led_bar.set_rgb(0, 120, 120, 0) # orange on LED0
    time.sleep(1.0)
    led_bar.set_rgb(0, 0, 120, 0) # green on LED0 
        
def writeControl():
    controlDictionary = {}
    controlDictionary.update({"animations" : animationDictionary})
    controlDictionary.update({"poses" : poseDictionary})

    with open("servoControl.json", "w") as outfile:
        json.dump(controlDictionary, outfile)    

    led_bar.set_rgb(1, 120, 120, 0) # orange on LED1
    time.sleep(1.0)
    led_bar.set_rgb(1, 0, 120, 0) # green on LED1

# first of all, try to load the servo map, it defines which channel drives which
# joint and how far that joint may travel. without it the firmware still runs,
# but nothing stops a bad host command from driving a joint into a hard stop.
mapLoaded = False
try:
    inJSON = ""
    with open("servoMap.json", 'r') as f:
        inJSON = f.read()

    if inJSON != "":
        inMap = json.loads(inJSON)

        for eachServo in inMap["servos"]:
            eachServoNumber = eachServo["index"]
            if eachServoNumber < TOTAL_SERVOS:
                servoMin[eachServoNumber] = eachServo["min"]
                servoMax[eachServoNumber] = eachServo["max"]
                servoEnabled[eachServoNumber] = eachServo["enabled"]

        # the map is only needed once, give the RAM back before loading the poses
        inMap = None
        inJSON = ""
        gc.collect()

        mapLoaded = True
        print("servoMap loaded")
        led_bar.set_rgb(2, 0, 120, 0) # green on LED2

    else:
        print("servoMap file empty")
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

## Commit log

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2022-09-07 added 3B_calf, freeCAD file, STL and Prusa gcode
    [3B_calf-Body.stl, 3B_calf.FCStd]
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2022-09-10 added 4R knee, now right foot upto the knee can be built
    [4R_knee-BodyFillet001.stl, 4R_knee.FCStd, 5R_hipjoint.FCStd]
2022-09-10 broadened 3F_shin after physically matching it to 2R_footjoint
    [3F_shin-Body.stl, 3F_shin.FCStd]
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2022-09-13 split 5R_hipjoint into two elements for better printability and iterability
    [3B_calf-Body.stl, 3B_calf.FCStd, 3F_shin.FCStd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]
2022-09-17 cleaned up some of the gcode and STL files, generated left foot, ankle, knee, calf by mirroring in freeCAD.
    [1L_foot-Body.stl, 1L_foot.FCStd, 2L_footJoint-Body.stl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]
2022-09-23 added left hip, cleaned up right hip / removed right hip general. cleaned up STL and gcode files.
    [5L_hipjoint_lower-Body.stl, 5L_hipjoint_lower.FCStd, 5L_hipjoint_upper-Body.stl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]
2022-09-24 added left and right hip parts as well as the front hip part.
    [6F_hipfront-Body.stl, 6F_hipfront.FCStd, 6L_hip-Body.stl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]
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2022-10-08 mini fix in micropython to make the servo controller's LED flas when receiving serial cmd.
    [usbServos.py]
2022-10-15 added commands for adding multiple poses and setting their servo values to interactiveServo.py, load and save works in all modes
    [servoValues.json]
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2022-10-29 added Store Named Pose command to usbServos.py and interactiveServo.py in preparation for animations on controller
    [servoValues.json]
2022-10-31 dumped pynput library and replaced it with curses library, decent tui now!
    [servoValues.json]
2022-10-31 added support for animations, esp navigation and editing. playback is missing
    [interactiveServo.py]
2022-11-01 support for animation adding, editing and playback. extended load / save to animations.
    [servoControl.json]
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2022-11-12 poses can now be highlighted in a list without activating them, press enter to send to controller
    [servoControl.json]
2022-11-12 changed usbServos.py to have the animations' poses also interpolated, i.e. at user defined speeds
    [servoControl.json]
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2022-11-19 6LR hip redesign for easier buildability
    [6F_hipfront.FCStd, 6L_hip-Body.stl, 6L_hip.FCStd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]
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2022-11-20 redesigned 4LR knee reducing the wobble
    [4L_knee-Body.stl, 4L_knee.FCStd, 4R_knee-Body.stl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]
2022-11-26 redesigned the feet (1LR) to reduce flimsiness
    [1L_foot-Body.stl, 1L_foot.FCStd, 1R_foot-Body.stl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]
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2022-12-03 modified the design of the lower hip to match the overall geometry.
    [5L_hipjoint_lower-Body.stl, 5L_hipjoint_lower.FCStd, 5R_hipjoint-Body.stl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]
2022-12-11 redesigned the calf to be less wobbly
    [3BL_calf-Body.stl, 3BL_calf.FCStd, 3BR_calf-Body.stl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]
2022-12-17 changed interactiveServo.py to accept backspace when entering text and added rename (r key) and delete (d) to the pose mode t rename or delete a pose.
    [servoControl.json]
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2023-02-12 redesigned 5 L and R lower hip joint to be assembled without nuts
    [5L_hipjoint_lower-Body.stl, 5L_hipjoint_lower.FCStd, 5R_hipjoint_lower-Body.stl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]
2023-02-19 adapted poses to Kayra with mouse pad rubber feet and added README.me for micropython directory.
    [servoControl.json]
2023-02-19 redesigned shins, for now to use for the upper shins to be stiffer and guide servo cables.
    [3FU_shin-Body.stl, 3FU_shin.FCStd]
2023-02-25 fine tuned shin again, please print 3FU for upper, and 3F for lower shin for the moment. further improved the feet to keep the ankle servos' weight in the middle of the foot
    [1L_foot-Body.stl, 1L_foot.FCStd, 1R_foot-Body.stl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]
2023-02-26 yesterday the left foot (STL and gcode) was front, here's an update
    [1L_foot-Body.stl, 2R_NEW_footJoint.FCStd]
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2023-05-18 changed software to work with 18 servos, added a couple of poses
    [servoControl.json, servoControlUpperBody.json]
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2023-06-11 added pose similarity to interactiveServo.py for suggesting similar poses in pose mode
    [servoControl.json]
2023-06-11 added support for missing IMU, i.e. controller also works when no IMU is installed
    [usbServosCluster.py]
2023-06-23 extended documentation, restructured software directories, added initial ESP32 PoC code for Wifi connection
    [servoControl.json, servoControlLowerBody.json, servoControlUpperBody.json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]
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2023-07-14 freeCAD files for neck & head as well as improvements for the host's interactiveServo.py and an update on the servoControl.json storing Kayra's first walk
    [ESP32CamCutOut-Body.stl, ESP32CamCutOut.FCStd, camAndDisplayHolder-Body.stl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]
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2023-07-29 head shell draft design, foot draft redesign, ESP32 I2C Wifi servo control software!
    [1R_foot_bearing_truss.FCStd, 1R_foot_bearing_truss_derived.FCStd, TVHead-Body.stl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]
2023-11-18 added directories 'simplified' to STL and 'mujoco' to base for entering the simulation field
    [1R_foot_bearing_truss_derived.FCStd, servoHorn.FCStd]
2023-11-18 added directories 'simplified' to STL and 'mujoco' to base for entering the simulation field and simplified foot
    [1R_foot-Body_simplified.stl]
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2023-11-18 added kayraLink.xml to mujoco dir, connected knee as base to shin via joint 2
    [kayraLink.xml]
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2023-11-19 added fourBars.xml and extended the readme to reflect all current knowledge about MuJoCo
    [fourBars.xml]
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2023-11-20 added right foot to MuJoCo, added position actuators to calf and foot
    [kayraCircle.xml]
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2023-11-26 added simulateAnimation.py to load physical Kayra's poses and play them back in MuJoCo
    [kayraLowerBody.xml]
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2023-12-18 redesigned knees to allow for full 90 bend
    [4L_knee-Body.stl, 4L_knee.FCStd, 4R_knee-Body.stl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]
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2023-12-22 changed mujoco kayra lower body's knee color to red to reflect the current printed version
    [kayraLowerBody.xml]
2024-01-05 updated all Kayra designs for foot, leg and hips. Reorganised STL,FCStd and gcode directories to distinguis between prototypes, old designs and obligatory, stable parts.
    [1L_foot-Body.stl, 1L_foot.FCStd, 1L_foot_bearing-BodySketch.stl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]
2024-01-06 adapted the orientation of the parts in MuJoCo after redesigning leg and hips, note that the positions are not updated yet
    [kayraLowerBody.xml]
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2024-01-07 corrected the foot and front ankle joints in position
    [kayraLowerBody.xml]
2024-01-08 updated collision parameters of kayra xml in mujoco for realistic collision
    [kayraLowerBody.xml]
2024-01-09 added servos, corrected a couple of joints in kayraLower XML for MuJoCo
    [kayraLowerBody.xml]
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2026-09-13 added servoMap.json as the single source for servo channel to joint mapping
    so far the servo channel numbers only had a meaning in the wiring and in a
    hardcoded block in mujoco/simulateAnimation.py. host, controller and simulation
    all passed around an anonymous vector of 18 floats. the inverse kinematics will
    need named joints, so the mapping is now a file that everybody reads.
    software/servoMap.json describes each of the 18 channels: joint name, side,
    kinematic chain, the printed part it drives, the corresponding MuJoCo actuator
    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
    [servoMap.json]
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2026-09-13 fixed the host dependencies and documented the PC setup
    the old requirements.txt could not be installed on a current Ubuntu: numpy was
    pinned to 1.26.4, which has no wheels beyond python 3.12, and future, iso8601
    and PyYAML were listed although nothing in the repository imports them.
    split the list in two, the simulation is supposed to be usable without any
    hardware so it should not pull in pyserial, and the host does not need mujoco:
    - software/requirements.txt pyserial, numpy
    - mujoco/requirements.txt mujoco plus what the extra scripts in that
    directory need, i.e. mujoco-python-viewer, matplotlib, opencv and mediapy
    minimum versions instead of exact pins so the lists survive python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
